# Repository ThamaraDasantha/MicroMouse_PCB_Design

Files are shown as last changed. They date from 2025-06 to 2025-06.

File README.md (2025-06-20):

# 🐭 Micromouse Robot – Custom PCB Design

This repository contains the **custom PCB design** for a Micromouse autonomous maze-solving robot. The design was inspired by the **Green Giant Micromouse**, a popular open-source project, and has been tailored to support modular, scalable, and competition-ready robotic development.

---

## 📦 Project Summary

Micromouse robots are small autonomous vehicles designed to solve mazes as quickly as possible. This PCB is the main controller board for such a robot, integrating motor drivers, sensors, power management, and microcontroller components in a compact footprint.

This design builds upon the **Green Giant Micromouse** architecture, with improvements for component sourcing, layout optimization, and modularity for further development.

---

## 🧠 Features & Specifications

| Category | Description |
|---|---|
| **Microcontroller** | STM32F4 / STM32F1 series (footprint supports both) |
| **Motor Drivers** | DRV8833 Dual H-Bridge for 2 DC motors |
| **Sensors** | IR distance sensors (front, left, right, 45 digree) – 5 sensors |
| **Power System** | 2-cell Li-ion with step-down regulator (5V and 3.3V rails)|
| **Connectivity** | Serial debug headers, encoder inputs, IR TX/RX support |
| **Form Factor** | Compact 2-layer PCB, optimized for wheel/motor layout |
| **Reference Design** | Based on Green Giant Micromouse with custom adaptations |

---

## 📐 PCB Design Overview

- Designed using **Eagle**
- Two-layer layout with clear separation of power and logic
- Silkscreen indicators for debugging and easy assembly
- Power and signal decoupling capacitors for noise stability
- Modular connector options for plugging in sensors and actuators

---

## 🧪 Testing & Next Steps

- Motor driver tested with small DC gear motors (30:1)
- Voltage rails tested with onboard regulators (5V and 3.3V)
- IR sensors and encoders interfaced with STM32 test code
- Future integration: PID motor control, maze-solving algorithm, IMU

---

## 📝 Acknowledgment

This design is heavily inspired by the [Green Giant Micromouse](https://github.com/davidtavarez/green-giant) project and adapted for educational and competitive use.

---

## 👨‍💻 Author

**Thamara Banneheka**  
Embedded Systems & Robotics Enthusiast  
📧 thamaradasantha@gmail.com  
🔗 [LinkedIn](https://www.linkedin.com/in/thamara-dasantha-banneheka/)

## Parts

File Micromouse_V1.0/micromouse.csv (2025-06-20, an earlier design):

Qty | Value | Device | Package | Parts | Description | ARROW_PART_NUMBER | ARROW_PRICE-STOCK | AVAILABILITY | CATEGORY | DESCRIPTION | HEIGHT | MANUFACTURER | MANUFACTURER_NAME | MANUFACTURER_PART_NUMBER | MF | MOUSER_PART_NUMBER | MOUSER_PRICE-STOCK | MP | MPN | OC_FARNELL | OC_NEWARK | OPERATING_TEMP | OPERATING_TEMPERATURE | PACKAGE | PART_STATUS | POPULARITY | PRICE | PROD_ID | RATING | ROHS_COMPLIANT | SERIES | SF_SKU | SPICEPREFIX | SUB-CATEGORY | SUB_CATEGORY | THERMALLOSS | TOLERANCE | TYPE | VALUE | VOLTAGE_RATING
1 |  | CONN_04X2 | 2X4 | J4 | Multi connection point. Often used as Generic Header-pin footprint for 0.1 inch spaced/style header connections
2 |  | JP1Q | JP1 | JP1, JP2 | JUMPER |  |  |  |  |  |  |  |  |  |  |  |  |  |  |  |  |  |  |  |  | 15
6 |  | LED0603 | LED-0603 | D11, D14, D17, D20, D22, D23 | LED (Generic)
2 |  | MA03-2 | MA03-2 | J2, J3 | PIN HEADER |  |  |  |  |  |  |  |  |  |  |  |  |  |  | unknown | unknown |  |  |  |  | 15
1 |  | PINHD-1X6 | 1X06 | JP3 | PIN HEADER
1 |  | SWITCH-SPDT-PTH-11.6X4.0MM | SWITCH_SPDT_PTH_11.6X4.0MM | S2 | Single Pole, Double Throw (SPDT) Switch |  |  |  |  |  |  |  |  |  |  |  |  |  |  |  |  |  |  |  |  |  |  | SWCH-08261 |  |  |  | COM-00102
1 | 0.01uF | C_CHIP-0805(2012-METRIC) | CAPC2012X110 | C_G1 | Capacitor - Generic |  |  |  | Capacitor
17 | 0.1uF | C_CHIP-0805(2012-METRIC) | CAPC2012X110 | C_5V4_4, C_EM2, C_EM3, C_EM5, C_EM7, C_EM10, C_EM12, C_G2, C_G3, C_M1, C_M5, C_RST, C_V1, C_V2, C_V3, C_V4, C_VA2 | Capacitor - Generic |  |  |  | Capacitor
17 | 0.1uf | C_CHIP-0805(2012-METRIC) | CAPC2012X110 | C3.3V_1, C5V_1, C5V_2, C5V_3, C5V_4, CNR, C_3.3V_6, C_A3.3V_1, C_A3.3V_3, C_B2, C_B3, C_B4, C_B7, C_DSP2, C_VBAT1, C_VBAT2, C_VBAT3 | Capacitor - Generic |  |  |  | Capacitor
5 | 0.75 ohm | R_CHIP-0603(1608-METRIC) | RESC1608X60 | R_R8, R_R10, R_R12, R_R14, R_R17 | Resistor Fixed - Generic |  |  |  | Resistor |  |  |  |  |  |  |  |  |  |  |  |  |  |  |  |  |  |  |  |  |  |  |  | R | Fixed
4 | 1.8k | R_CHIP-0603(1608-METRIC) | RESC1608X60 | R_R2, R_R4, R_R6, R_R7 | Resistor Fixed - Generic |  |  |  | Resistor |  |  |  |  |  |  |  |  |  |  |  |  |  |  |  |  |  |  |  |  |  |  |  | R | Fixed
1 | 10 uH | L-USL4035M | L4035M | L1 | INDUCTOR, American symbol |  |  |  |  |  |  |  |  |  |  |  |  |  |  |  |  |  |  |  |  | 0 |  |  |  |  |  |  | L
1 | 100K | R_CHIP-0603(1608-METRIC) | RESC1608X60 | R_B1 | Resistor Fixed - Generic |  |  |  | Resistor |  |  |  |  |  |  |  |  |  |  |  |  |  |  |  |  |  |  |  |  |  |  |  | R | Fixed
2 | 100uF | C_CHIP-0805(2012-METRIC) | CAPC2012X110 | C_MB_L, C_MB_R | Capacitor - Generic |  |  |  | Capacitor
1 | 100uf | C_CHIP-0805(2012-METRIC) | CAPC2012X110 | C_5V_1 | Capacitor - Generic |  |  |  | Capacitor
2 | 10K | R_CHIP-0603(1608-METRIC) | RESC1608X60 | R_B5, R_PG1 | Resistor Fixed - Generic |  |  |  | Resistor |  |  |  |  |  |  |  |  |  |  |  |  |  |  |  |  |  |  |  |  |  |  |  | R | Fixed
16 | 10k | R_CHIP-0603(1608-METRIC) | RESC1608X60 | R_FBB2, R_LED1_PULLUP, R_LED1_PULLUP1, R_LED1_PULLUP2, R_LED1_PULLUP3, R_PWMUP3, R_PWMUP4, R_PWMUP_1, R_PWMUP_2, R_R9, R_R11, R_R13, R_R15, R_R16, R_R18, R_VM2 | Resistor Fixed - Generic |  |  |  | Resistor |  |  |  |  |  |  |  |  |  |  |  |  |  |  |  |  |  |  |  |  |  |  |  | R | Fixed
1 | 10uF | C_CHIP-0805(2012-METRIC) | CAPC2012X110 | C_EM11 | Capacitor - Generic |  |  |  | Capacitor
1 | 10uH | L-USL4035M | L4035M | L3 | INDUCTOR, American symbol |  |  |  |  |  |  |  |  |  |  |  |  |  |  |  |  |  |  |  |  | 0 |  |  |  |  |  |  | L
4 | 10uf | C_CHIP-0805(2012-METRIC) | CAPC2012X110 | C3.3V_7, C_3.3V_5, C_DSP1, C_DSP3 | Capacitor - Generic |  |  |  | Capacitor
1 | 115K | R_CHIP-0603(1608-METRIC) | RESC1608X60 | RB1 | Resistor Fixed - Generic |  |  |  | Resistor |  |  |  |  |  |  |  |  |  |  |  |  |  |  |  |  |  |  |  |  |  |  |  | R | Fixed
1 | 150K | R_CHIP-0603(1608-METRIC) | RESC1608X60 | R_B2 | Resistor Fixed - Generic |  |  |  | Resistor |  |  |  |  |  |  |  |  |  |  |  |  |  |  |  |  |  |  |  |  |  |  |  | R | Fixed
3 | 1K | R_CHIP-0603(1608-METRIC) | RESC1608X60 | R_LED8, R_LED9, R_PWR1 | Resistor Fixed - Generic |  |  |  | Resistor |  |  |  |  |  |  |  |  |  |  |  |  |  |  |  |  |  |  |  |  |  |  |  | R | Fixed
1 | 1N4148WSQ-13-F | 1N4148WSQ-13-F | SOD2513X120N | D7 | SURFACE MOUNT FAST SWITCHING DIODE | 1N4148WSQ-13-F | https://www.arrow.com/en/products/1n4148wsq-13-f/diodes-incorporated |  |  | SURFACE MOUNT FAST SWITCHING DIODE | 1.2mm |  | Diodes Inc. | 1N4148WSQ-13-F |  | N/A | https://www.mouser.com/Search/Refine.aspx?Keyword=N%2FA
1 | 2.2 uH | L-USL4035M | L4035M | L6 | INDUCTOR, American symbol |  |  |  |  |  |  |  |  |  |  |  |  |  |  |  |  |  |  |  |  | 0 |  |  |  |  |  |  | L
10 | 2.2uF | C_CHIP-0805(2012-METRIC) | CAPC2012X110 | C_BAT, C_G4, C_VA1, C_VA3, C_VA4, C_VA6, C_VA8, C_VA9, C_VCAP1, C_VCAP2 | Capacitor - Generic |  |  |  | Capacitor
2 | 2.2uf | C_CHIP-0805(2012-METRIC) | CAPC2012X110 | C_A3.3V, C_B5 | Capacitor - Generic |  |  |  | Capacitor
1 | 22 pf | C_CHIP-0805(2012-METRIC) | CAPC2012X110 | C_B10 | Capacitor - Generic |  |  |  | Capacitor
1 | 223K | R_CHIP-0603(1608-METRIC) | RESC1608X60 | RT1 | Resistor Fixed - Generic |  |  |  | Resistor |  |  |  |  |  |  |  |  |  |  |  |  |  |  |  |  |  |  |  |  |  |  |  | R | Fixed
5 | 330 ohm | R_CHIP-0603(1608-METRIC) | RESC1608X60 | R_LED1, R_LED2, R_LED3, R_LED4, R_LED7 | Resistor Fixed - Generic |  |  |  | Resistor |  |  |  |  |  |  |  |  |  |  |  |  |  |  |  |  |  |  |  |  |  |  |  | R | Fixed
1 | 3300pF | C_CHIP-0805(2012-METRIC) | CAPC2012X110 | C_SS1 | Capacitor - Generic |  |  |  | Capacitor
1 | 35.7K | R_CHIP-0603(1608-METRIC) | RESC1608X60 | R_B3 | Resistor Fixed - Generic |  |  |  | Resistor |  |  |  |  |  |  |  |  |  |  |  |  |  |  |  |  |  |  |  |  |  |  |  | R | Fixed
1 | 3A/250V | B2B-XH-A | B2B-XH-A | J1 | XH Connector Top Entry - 2POS |  |  |  | CONNECTOR | 2.5mm pitch/disconnectable crimp style connector |  | JST (XH CONNECTOR) |  |  |  |  |  |  | B2B-XH-A |  |  |  | -25°C ~ 85°C |  | ACTIVE |  |  |  |  | COMPLIANT | B_B-XH-A |  | B |  | Through hole connector |  |  | top entry | 3A/250V
5 | 4.7 uH | L-USL4035M | L4035M | L2, L4, L5, L7, XFL4020 | INDUCTOR, American symbol |  |  |  |  |  |  |  |  |  |  |  |  |  |  |  |  |  |  |  |  | 0 |  |  |  |  |  |  | L
2 | 4.7k | R_CHIP-0603(1608-METRIC) | RESC1608X60 | R_R1, R_VM1 | Resistor Fixed - Generic |  |  |  | Resistor |  |  |  |  |  |  |  |  |  |  |  |  |  |  |  |  |  |  |  |  |  |  |  | R | Fixed
7 | 4.7uF | C_CHIP-0805(2012-METRIC) | CAPC2012X110 | C_EM1, C_EM4, C_EM6, C_EM8, C_EM9, C_M2, C_M4 | Capacitor - Generic |  |  |  | Capacitor
1 | 470 pf | C_CHIP-0805(2012-METRIC) | CAPC2012X110 | C_B6 | Capacitor - Generic |  |  |  | Capacitor
1 | 470uf | C_CHIP-0805(2012-METRIC) | CAPC2012X110 | CVC1 | Capacitor - Generic |  |  |  | Capacitor
1 | 47K | R_CHIP-0603(1608-METRIC) | RESC1608X60 | R_LED6 | Resistor Fixed - Generic |  |  |  | Resistor |  |  |  |  |  |  |  |  |  |  |  |  |  |  |  |  |  |  |  |  |  |  |  | R | Fixed
1 | 47uF | C_CHIP-0805(2012-METRIC) | CAPC2012X110 | C5V4_5 | Capacitor - Generic |  |  |  | Capacitor
5 | 47uf | C_CHIP-0805(2012-METRIC) | CAPC2012X110 | C3.3V_2, C_B1, C_B8, C_B9, C_VBAT4 | Capacitor - Generic |  |  |  | Capacitor
1 | 52.5K | R_CHIP-0603(1608-METRIC) | RESC1608X60 | R_FBT1 | Resistor Fixed - Generic |  |  |  | Resistor |  |  |  |  |  |  |  |  |  |  |  |  |  |  |  |  |  |  |  |  |  |  |  | R | Fixed
1 | 94.65K | R_CHIP-0603(1608-METRIC) | RESC1608X60 | R_B4 | Resistor Fixed - Generic |  |  |  | Resistor |  |  |  |  |  |  |  |  |  |  |  |  |  |  |  |  |  |  |  |  |  |  |  | R | Fixed
1 | GREEN | LEDCHIPLED_0603 | CHIPLED_0603 | PWR_LED1 | LED |  |  |  |  |  |  |  |  |  |  |  |  |  |  |  |  |  |  |  |  |  |  |  |  |  |  |  | B
1 | HCMS-2903 | HCMS-2903 | DIPS762W64P254L1778H508Q12N | DS1 | HCMS-2903 Avago 4 Digit Alphanumeric LED Display, 7 x 5 Dot Matrix Green 114 ucd 3.7mm |  |  |  |  | HCMS-2903 Avago 4 Digit Alphanumeric LED Display, 7 x 5 Dot Matrix Green 114 ucd 3.7mm | 5.08mm |  | Avago Technologies | HCMS-2903 |  | 630-HCMS-2903 | https://www.mouser.co.uk/ProductDetail/Broadcom-Avago/HCMS-2903?qs=xnajaXqBF98aIaDe8yGItA%3D%3D
2 | KMR211G | KMR211G | KMR211G | S1, S3 | Tactile Switch SPST-NO Top Actuated Surface Mount, Microminiature 40 N (8.8 lbs) during 25,000 cycles |  |  |  |  | Tactile Switch SPST-NO Top Actuated Surface Mount, Microminiature 40 N (8.8 lbs) during 25,000 cycles | 1.9mm |  | ITT CANNON | KMR211G
1 | LMZ10501SILR | LMZ10501SILR | SON65P260X300X150-9N | IC3 | Non-Isolated DC/DC Converters 1A Nano Mod w/ 5.5V Max Inpt VTG | LMZ10501SILR | https://www.arrow.com/en/products/lmz10501silr/texas-instruments |  |  | Non-Isolated DC/DC Converters 1A Nano Mod w/ 5.5V Max Inpt VTG | 1.5mm |  | Texas Instruments | LMZ10501SILR |  | 595-LMZ10501SILR | https://www.mouser.co.uk/ProductDetail/Texas-Instruments/LMZ10501SILR?qs=wqe5ZXqX%252B99mwpjk8%252BrPBA%3D%3D |  |  |  |  |  |  |  |  |  |  |  |  |  |  |  | X
1 | LMZ21701SILT | LMZ21701SILT | LMZ21701SILT | IC1 | 3V to 17V, 1A Step-Down DC/DC Power Module in 3.5mm 3.5mm Package | LMZ21701SILT | https://www.arrow.com/en/products/lmz21701silt/texas-instruments?region=nac |  |  | 3V to 17V, 1A Step-Down DC/DC Power Module in 3.5mm 3.5mm Package | 1.75mm |  | Texas Instruments | LMZ21701SILT |  | 595-LMZ21701SILT | https://www.mouser.co.uk/ProductDetail/Texas-Instruments/LMZ21701SILT?qs=%2Fd%252BFzHvH4c3T8wa09brf8Q%3D%3D |  |  |  |  |  |  |  |  |  |  |  |  |  |  |  | X
1 | MCP1700T-5002E_TT | MCP1700T-5002E_TT | SOT95P237X112-3N | IC4 | LDO Regulator 250mA 5.0V 1.6uA SOT23 | MCP1700T-5002E/TT | https://www.arrow.com/en/products/mcp1700t-5002ett/microchip-technology?region=nac |  |  | LDO Regulator 250mA 5.0V 1.6uA SOT23 | 1.12mm |  | Microchip | MCP1700T-5002E/TT |  | 579-MCP1700T5002E/TT | https://www.mouser.co.uk/ProductDetail/Microchip-Technology-Atmel/MCP1700T-5002E-TT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 |  |  |  |  |  |  |  |  |  |  |  |  |  |  |  | J
1 | MPU-6500 | MPU-6500 | QFN40P300X300X95-25N | IC7 | IMUs - Inertial Measurement Units 6-Axis MEMS MotionTracking Device with DMP | MPU-6500 | https://www.arrow.com/en/products/mpu-6500/invensense?region=nac |  |  | IMUs - Inertial Measurement Units 6-Axis MEMS MotionTracking Device with DMP | 0.95mm |  | TDK | MPU-6500 |  | 410-MPU-6500 | https://www.mouser.co.uk/ProductDetail/TDK-InvenSense/MPU-6500?qs=u4fy%2FsgLU9PiIOIlWOSPhQ%3D%3D
5 | SFH_4545 | SFH_4545 | DIO_SFH_4545 | D1, D2, D3, D4, D5 | High Power Infrared Emitter (940 nm) Check availability |  |  | In Stock |  | Infrared (IR) Emitter 950nm 1.5V 100mA 550mW/sr @ 100mA 10° Radial |  |  |  |  | OSRAM Opto |  |  | SFH 4545 |  |  |  |  |  | Radial Osram Opto |  |  | None
1 | SMT-0540-S-R | SMT-0540-S-R | SMT0540SR | LS1 | Speakers & Transducers SMD TRANSDUCER 3VP-P 100MA |  |  |  |  | Speakers & Transducers SMD TRANSDUCER 3VP-P 100MA | 2mm |  | PUI Audio | SMT-0540-S-R |  | 665-SMT0540SR | https://www.mouser.co.uk/ProductDetail/PUI-Audio/SMT-0540-S-R?qs=e16JbV5WBEu5VaDVzQP23Q%3D%3D
10 | SSM3K324R | SSM3K324R | SOT95P240X88-3N | Q10, Q11, Q12, Q13, Q14, Q15, Q18, Q19, Q20, Q21 | MOSFET N-Ch 4A SOT-23F-3 |  |  |  |  | MOSFET N-Ch 4A SOT-23F-3 | 0.88mm |  | Toshiba | SSM3K324R
1 | STM32F405RGT6V | STM32F405RGT6V | QFP50P1200X1200X160-64N | IC9 | STMicroelectronics, STM32F405RGT6V STM32F405RGT6V, 32 bit ARM Cortex M4 MCU 168MHz 1024 kB Flash, 192 + 4 kB RAM, USB CAN I2C 64-Pin LQFP | STM32F405RGT6V | https://www.arrow.com/en/products/stm32f405rgt6v/stmicroelectronics?region=nac |  |  | STMicroelectronics, STM32F405RGT6V STM32F405RGT6V, 32 bit ARM Cortex M4 MCU 168MHz 1024 kB Flash, 192 + 4 kB RAM, USB CAN I2C 64-Pin LQFP | 1.6mm |  | STMicroelectronics | STM32F405RGT6V |  | 511-STM32F405RGT6V | https://www.mouser.co.uk/ProductDetail/STMicroelectronics/STM32F405RGT6V?qs=gNDSiZmRJS%2FlL0isCSU2mg%3D%3D
5 | TEFT4300 | TEFT4300 | TEFT4300 | Q3, Q4, Q6, Q8, Q9 | Vishay TEFT4300 60 Infrared Phototransistor, Through-hole 3mm Package | TEFT4300 | https://www.arrow.com/en/products/teft4300/vishay |  |  | Vishay TEFT4300 60 Infrared Phototransistor, Through-hole 3mm Package | 6.1mm |  | Vishay | TEFT4300 |  | 782-TEFT4300 | https://www.mouser.co.uk/ProductDetail/Vishay-Semiconductors/TEFT4300?qs=HsFHTXumnCRbcrt8oPFPMA%3D%3D
1 | TPS61088RHLT | TPS61088RHLT | BQ24031IRHLRQ1 | IC8 | Texas Instruments TPS61088RHLT, 3, Boost Converter, Synchronous Boost Converter 10A 4.5 12.6 V, 2.2 MHz 20-Pin | TPS61088RHLT | https://www.arrow.com/en/products/tps61088rhlt/texas-instruments?region=nac |  |  | Texas Instruments TPS61088RHLT, 3, Boost Converter, Synchronous Boost Converter 10A 4.5 12.6 V, 2.2 MHz 20-Pin | 1mm |  | Texas Instruments | TPS61088RHLT |  | 595-TPS61088RHLT | https://www.mouser.co.uk/ProductDetail/Texas-Instruments/TPS61088RHLT?qs=MiqG6Kq1qKOeAwvWtl5eUw%3D%3D
1 | TPS73633MDBVREPG4 | TPS73633MDBVREPG4 | SOT95P280X145-5N | IC2 | LOW-DROPOUT REGULATORS | TPS73633MDBVREPG4 | https://www.arrow.com/en/products/tps73633mdbvrepg4/texas-instruments |  |  | LOW-DROPOUT REGULATORS | 1.45mm |  | Texas Instruments | TPS73633MDBVREPG4 |  | 595-PS73633MDBVREPG4 | https://www.mouser.co.uk/ProductDetail/Texas-Instruments/TPS73633MDBVREPG4?qs=OaSNdy%2FNfzkIGdo0ZU34AA%3D%3D |  |  |  |  |  |  |  |  |  |  |  |  |  |  |  | X
2 | UCC27524DR | UCC27524DR | SOIC127P600X175-8N | IC5, IC6 | Dual, 5A, High-Speed Low-Side Power MOSFET Driver | UCC27524DR | https://www.arrow.com/en/products/ucc27524dr/texas-instruments?region=nac |  |  | Dual, 5A, High-Speed Low-Side Power MOSFET Driver | 1.75mm |  | Texas Instruments | UCC27524DR |  | 595-UCC27524DR | https://www.mouser.co.uk/ProductDetail/Texas-Instruments/UCC27524DR?qs=iuXUNOC6nYdK8rrTqka0jA%3D%3D
2 | ZXMHC3F381N8TC | ZXMHC3F381N8TC | SOIC127P600X175-8N | Q1, Q2 | MOSFET Dual N/P-Ch 30V 4.98A/4.13A SOIC8 Diodes Inc ZXMHC3F381N8TC Quad N/P-channel MOSFET Transistor, 8-Pin SO | ZXMHC3F381N8TC | https://www.arrow.com/en/products/zxmhc3f381n8tc/diodes-incorporated?region=nac |  |  | MOSFET Dual N/P-Ch 30V 4.98A/4.13A SOIC8 Diodes Inc ZXMHC3F381N8TC Quad N/P-channel MOSFET Transistor, 8-Pin SO | 1.75mm |  | Diodes Inc. | ZXMHC3F381N8TC |  | 522-ZXMHC3F381N8TC | https://www.mouser.co.uk/ProductDetail/Diodes-Incorporated/ZXMHC3F381N8TC?qs=7E5rbXJDVJoJr15tcLBfrA%3D%3D

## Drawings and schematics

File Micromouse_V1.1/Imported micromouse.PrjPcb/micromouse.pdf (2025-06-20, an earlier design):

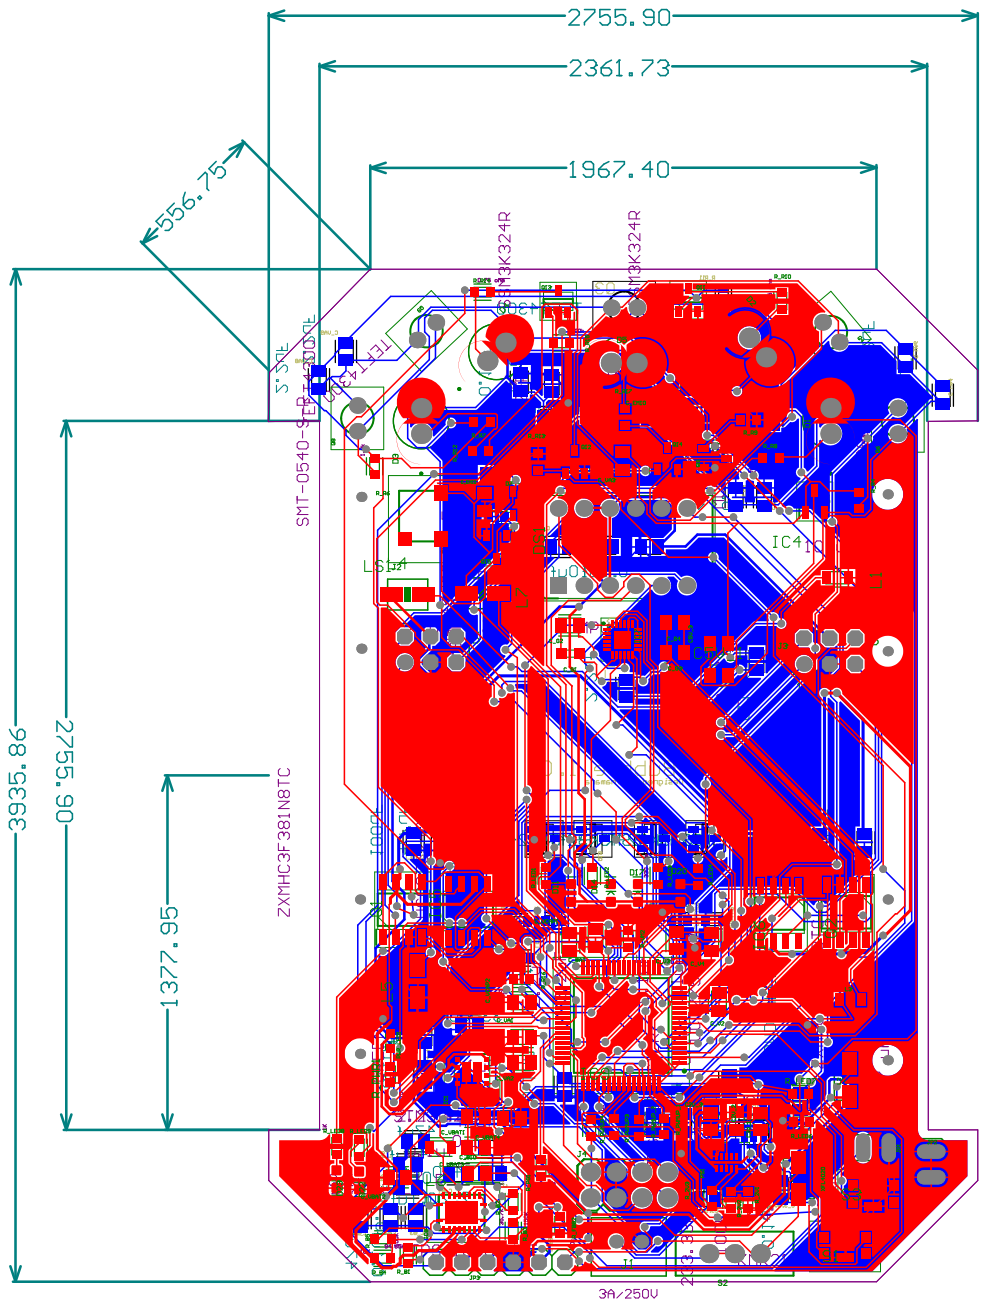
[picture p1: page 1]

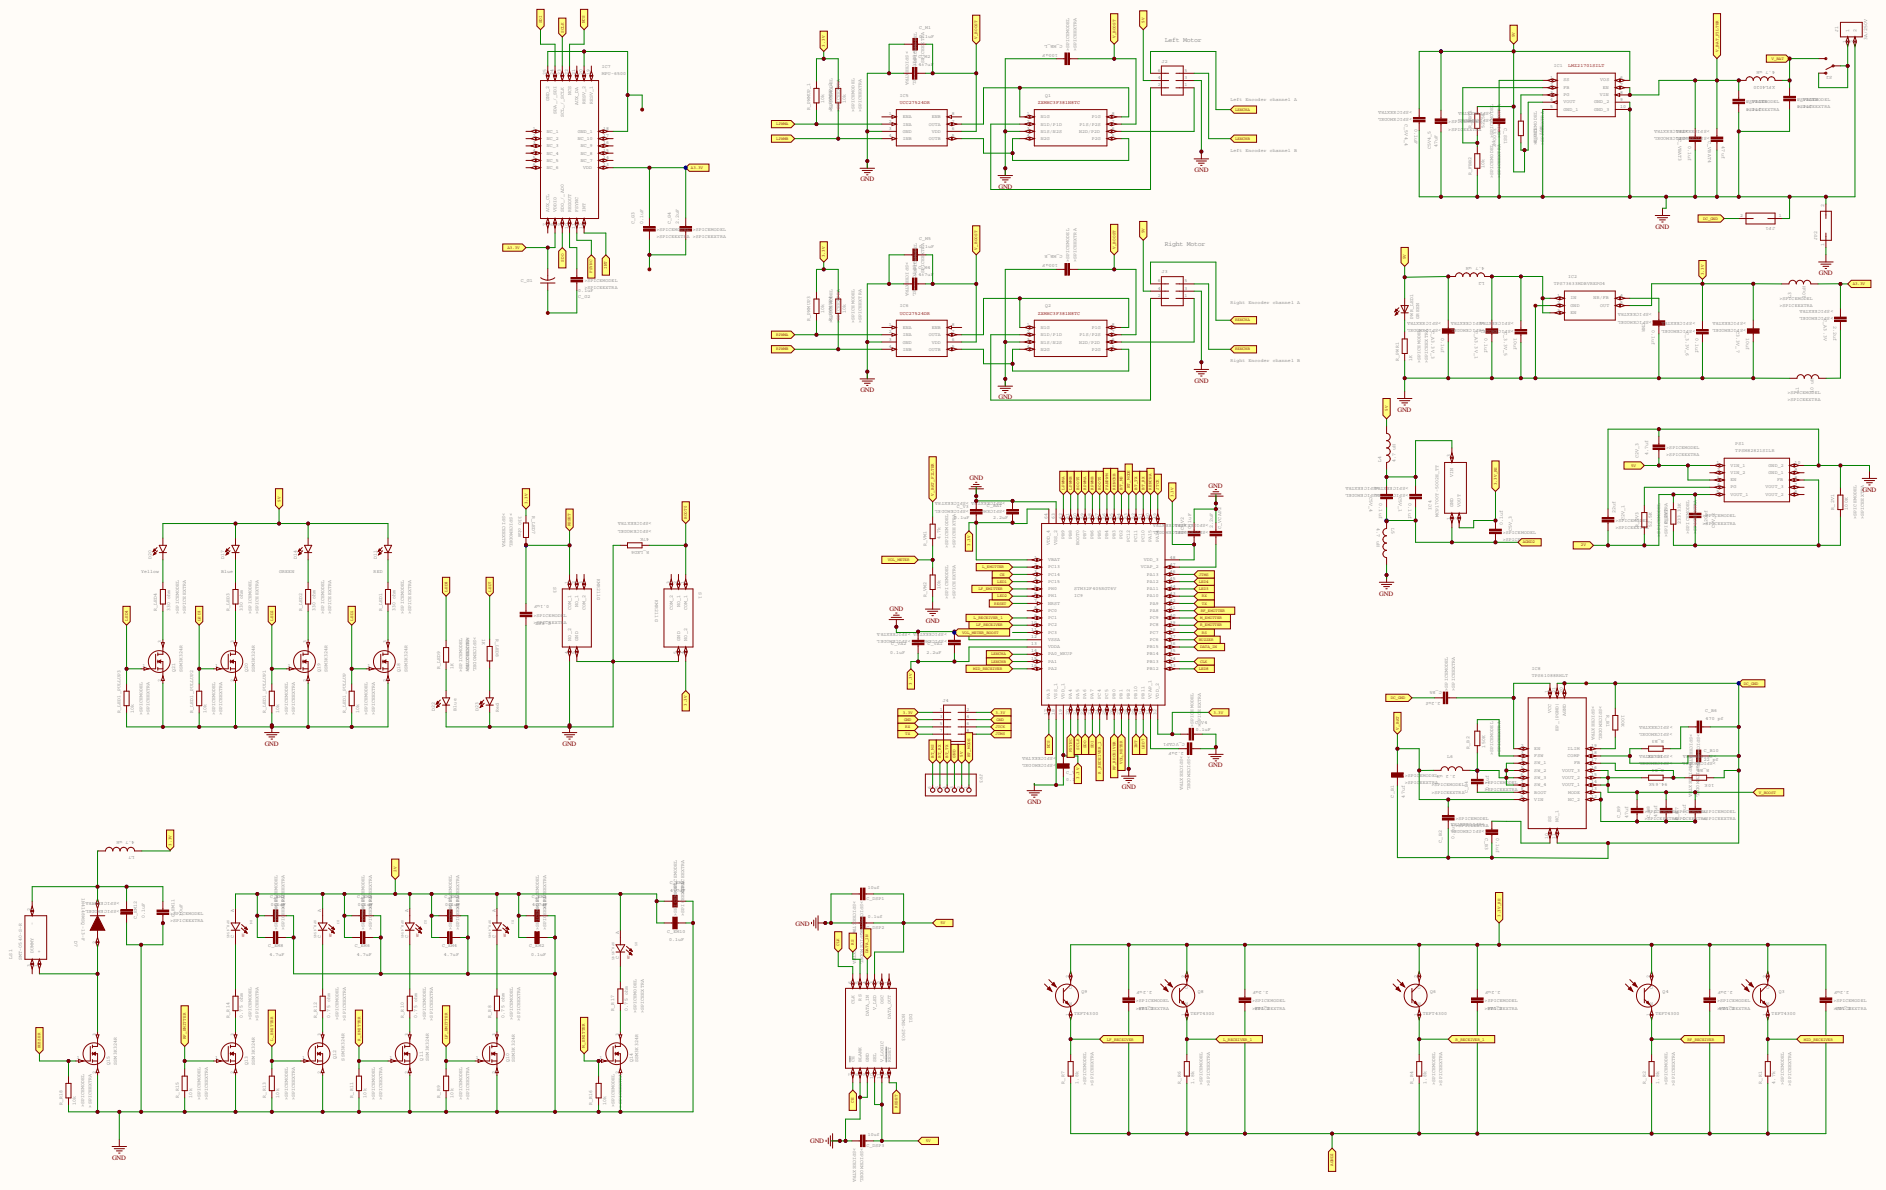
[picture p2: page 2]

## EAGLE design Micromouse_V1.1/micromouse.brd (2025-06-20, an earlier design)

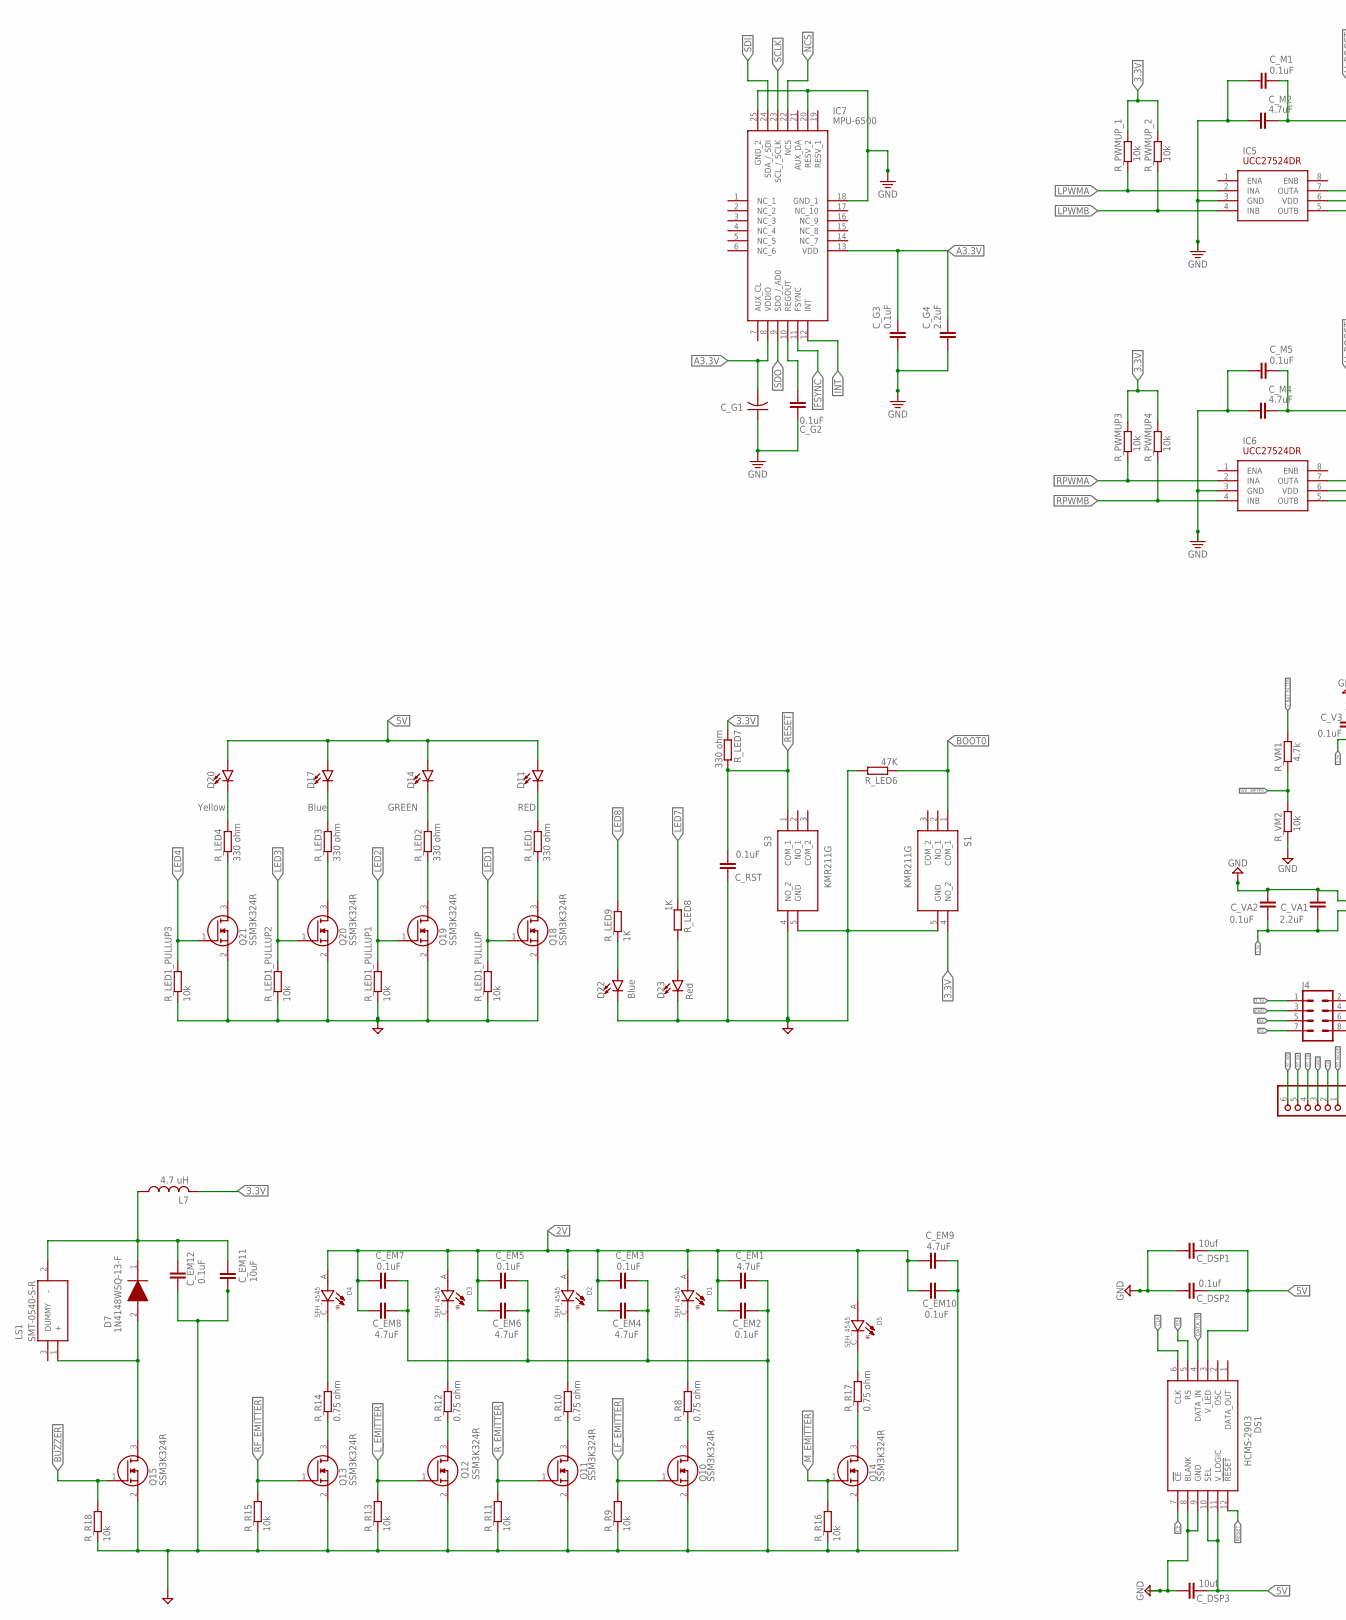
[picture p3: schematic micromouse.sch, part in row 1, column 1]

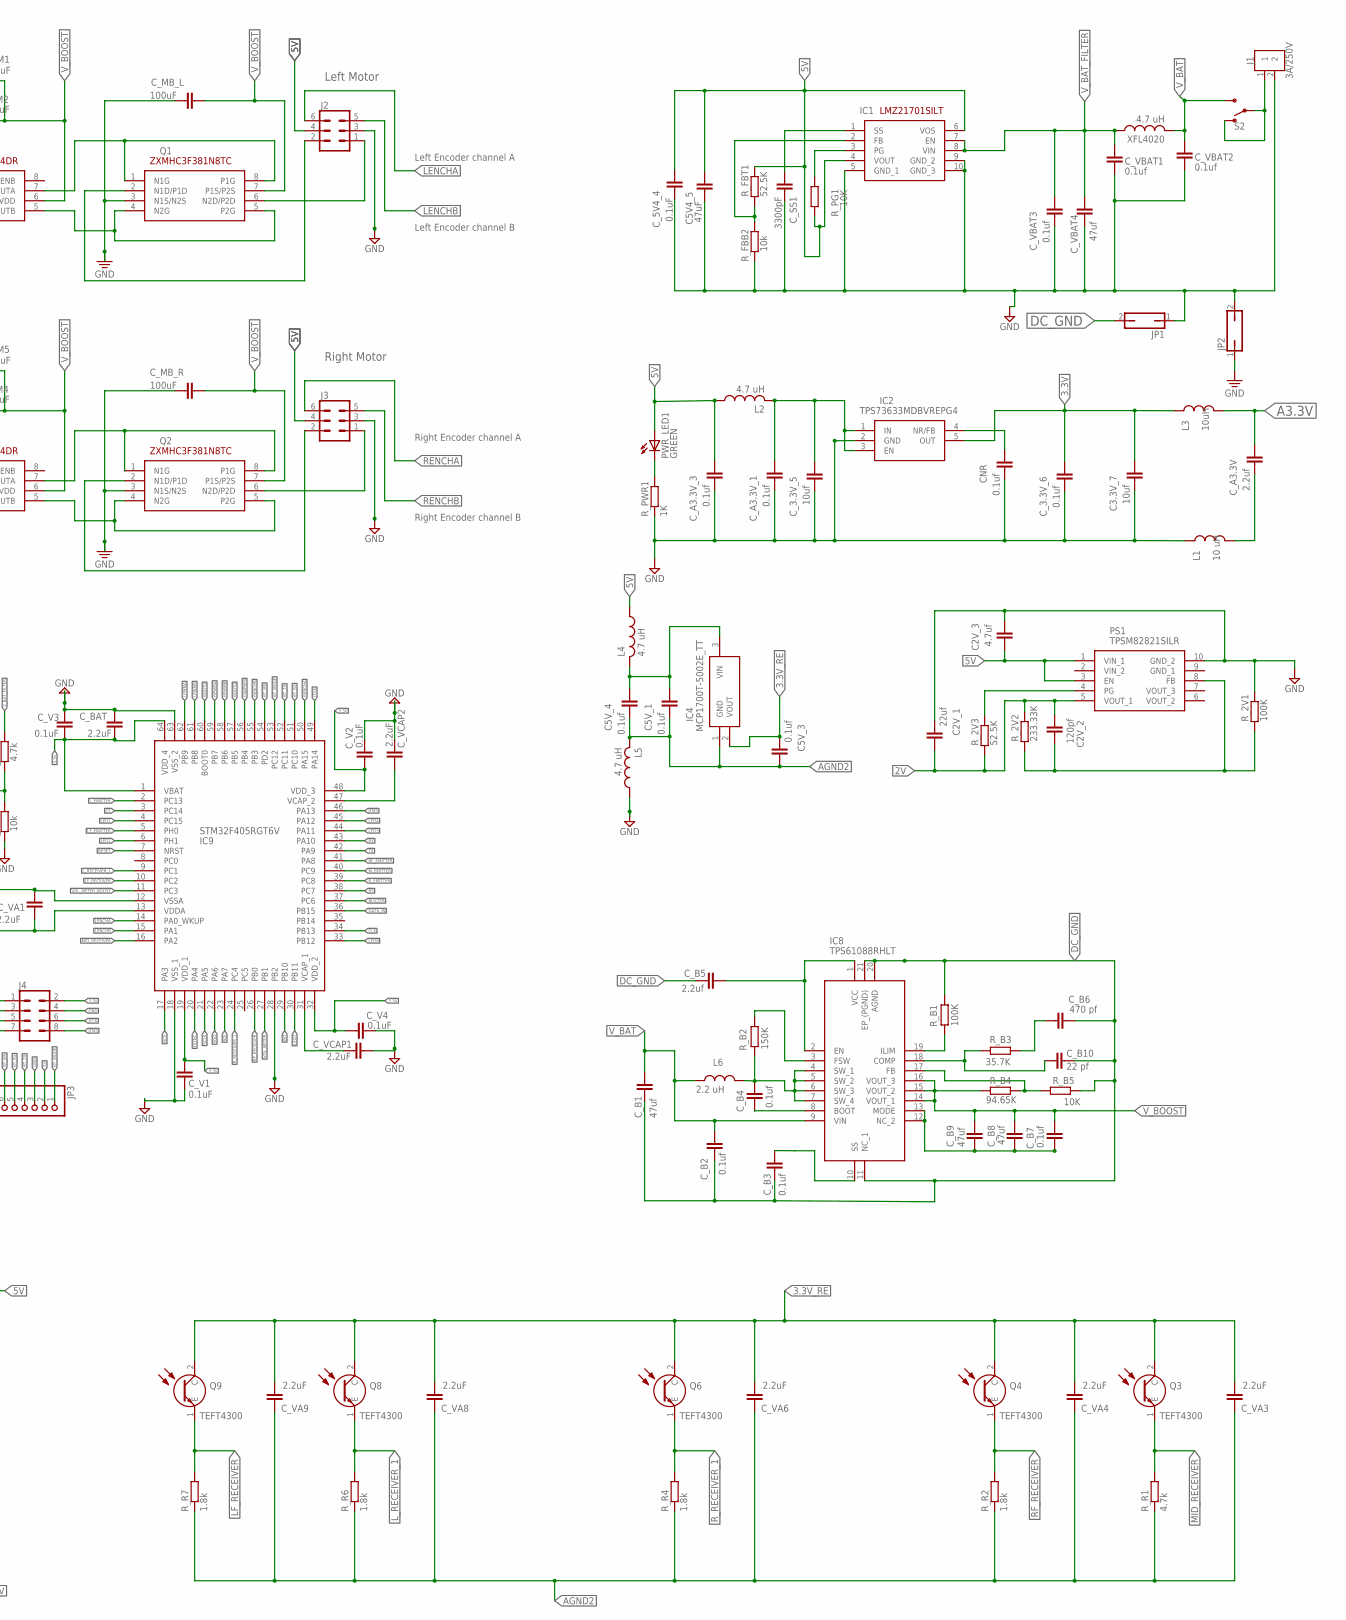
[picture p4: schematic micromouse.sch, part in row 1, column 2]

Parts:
C2V_1: 22uf; CAPC2012X110
C2V_2: 120pf; CAPC2012X110
C2V_3: 4.7uf; CAPC2012X110
C3.3V_7: 10uf; CAPC2012X110
C5V4_5: 47uF; CAPC2012X110
C5V_1, C5V_3, C5V_4: 0.1uf; CAPC2012X110
CNR: 0.1uf; CAPC2012X110
C_3.3V_5: 10uf; CAPC2012X110
C_3.3V_6: 0.1uf; CAPC2012X110
C_5V4_4: 0.1uF; CAPC2012X110
C_A3.3V: 2.2uf; CAPC2012X110
C_A3.3V_1, C_A3.3V_3: 0.1uf; CAPC2012X110
C_B1, C_B8, C_B9: 47uf; CAPC2012X110
C_B2, C_B3, C_B4, C_B7: 0.1uf; CAPC2012X110
C_B5: 2.2uf; CAPC2012X110
C_B6: 470 pf; CAPC2012X110
C_B10: 22 pf; CAPC2012X110
C_BAT: 2.2uF; CAPC2012X110
C_DSP1, C_DSP3: 10uf; CAPC2012X110
C_DSP2: 0.1uf; CAPC2012X110
C_EM1, C_EM4, C_EM6, C_EM8, C_EM9: 4.7uF; CAPC2012X110
C_EM2, C_EM3, C_EM5, C_EM7, C_EM10, C_EM12: 0.1uF; CAPC2012X110
C_EM11: 10uF; CAPC2012X110
C_G1: 0.01uF; C0603K
C_G2, C_G3: 0.1uF; CAPC2012X110
C_G4: 2.2uF; CAPC2012X110
C_M1, C_M5: 0.1uF; CAPC2012X110
C_M2, C_M4: 4.7uF; CAPC2012X110
C_MB_L: 100uF; CAPC2012X110
C_MB_R: 100uF; CAPC2012X110
C_RST: 0.1uF; CAPC2012X110
C_SS1: 3300pF; CAPC2012X110
C_V1, C_V2, C_V3, C_V4: 0.1uF; CAPC2012X110
C_VA1, C_VA3, C_VA4, C_VA6, C_VA8, C_VA9: 2.2uF; CAPC2012X110
C_VA2: 0.1uF; CAPC2012X110
C_VBAT1, C_VBAT2, C_VBAT3: 0.1uf; CAPC2012X110
C_VBAT4: 47uf; CAPC2012X110
C_VCAP1, C_VCAP2: 2.2uF; CAPC2012X110
D1, D2, D3, D4, D5: SFH_4545; DIO_SFH_4545
D7: 1N4148WSQ-13-F; SOD2513X120N
D11, D14, D17, D20, D22, D23: LED0603; LED-0603
DS1: HCMS-2903; DIPS762W64P254L1778H508Q12N
IC1: LMZ21701SILT
IC2: TPS73633MDBVREPG4; SOT95P280X145-5N
IC4: MCP1700T-5002E_TT; SOT95P237X112-3N
IC5, IC6: UCC27524DR; SOIC127P600X175-8N
IC7: MPU-6500; QFN40P300X300X95-25N
IC8: TPS61088RHLT; BQ24031IRHLRQ1
IC9: STM32F405RGT6V; QFP50P1200X1200X160-64N
J1: 3A/250V; B2B-XH-A
J2, J3: MA03-2
J4: CONN_04X2; 2X4
JP1, JP2: JP1Q; JP1
JP3: PINHD-1X6; 1X06
L1: 10 uH; INDC2009X120
L2, L4, L5, L7: 4.7 uH; L4035M
L3: 10uH; INDC2009X120
L6: 2.2 uH; INDC2009X120
LS1: SMT-0540-S-R; SMT0540SR
PS1: TPSM82821SILR
PWR_LED1: GREEN; CHIPLED_0603
Q1, Q2: ZXMHC3F381N8TC; SOIC127P600X175-8N
Q3, Q4, Q6, Q8, Q9: TEFT4300
Q10, Q11, Q12, Q13, Q14, Q15, Q18, Q19, Q20, Q21: SSM3K324R; SOT95P240X88-3N
R_2V1: 100K; RESC1608X60
R_2V2: 233.33K; RESC1608X60
R_2V3: 52.5K; RESC1608X60
R_B1: 100K; RESC1608X60
R_B2: 150K; RESC1608X60
R_B3: 35.7K; RESC1608X60
R_B4: 94.65K; RESC1608X60
R_B5: 10K; RESC1608X60
R_FBB2: 10k; RESC1608X60
R_FBT1: 52.5K; RESC1608X60
R_LED1, R_LED2, R_LED3, R_LED4, R_LED7: 330 ohm; RESC1608X60
R_LED1_PULLUP, R_LED1_PULLUP1, R_LED1_PULLUP2, R_LED1_PULLUP3: 10k; RESC1608X60
R_LED6: 47K; RESC1608X60
R_LED8, R_LED9: 1K; RESC1608X60
R_PG1: 10K; RESC1608X60
R_PWMUP3, R_PWMUP4: 10k; RESC1608X60
R_PWMUP_1, R_PWMUP_2: 10k; RESC1608X60
R_PWR1: 1K; RESC1608X60
R_R1: 4.7k; RESC1608X60
R_R2, R_R4, R_R6, R_R7: 1.8k; RESC1608X60
R_R8, R_R10, R_R12, R_R14, R_R17: 0.75 ohm; RESC1608X60
R_R9, R_R11, R_R13, R_R15, R_R16, R_R18: 10k; RESC1608X60
R_VM1: 4.7k; RESC1608X60
R_VM2: 10k; RESC1608X60
S1, S3: KMR211G
S2: SWITCH-SPDT-PTH-11.6X4.0MM; SWITCH_SPDT_PTH_11.6X4.0MM
XFL4020: 4.7 uH; L4035M

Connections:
2V: C2V_1.2, C2V_2.1, C_EM1.1, C_EM2.1, C_EM3.1, C_EM4.1, C_EM5.1, C_EM6.1, C_EM7.1, C_EM8.1, C_EM9.1, C_EM10.1, D1.A, D2.A, D3.A, D4.A, D5.A, PS1.5 (VOUT_1), R_2V2.2, R_2V3.1
3.3V: C3.3V_7.2, C_3.3V_6.2, C_BAT.1, C_V1.2, C_V2.1, C_V3.1, C_V4.1, C_VA1.1, C_VA2.1, IC2.5 (OUT), IC9.1 (VBAT), IC9.13 (VDDA), IC9.19 (VDD_1), IC9.32 (VDD_2), IC9.48 (VDD_3), IC9.64 (VDD_4), J4.1, J4.2, L3.1, L7.2, R_LED7.1, R_PWMUP3.2, R_PWMUP4.2, R_PWMUP_1.2, R_PWMUP_2.2, S1.4 (NO_2)
3.3V_RE: C5V_3.1, C_VA3.1, C_VA4.1, C_VA6.1, C_VA8.1, C_VA9.1, IC4.2 (VOUT), Q3.2 (C), Q4.2 (C), Q6.2 (C), Q8.2 (C), Q9.2 (C)
5V: C2V_3.2, C5V4_5.1, C_5V4_4.2, C_A3.3V_3.2, C_DSP1.1, C_DSP2.1, C_DSP3.1, D11.A, D14.A, D17.A, D20.A, DS1.3 (V_LED), DS1.10 (SEL), DS1.11 (V_LOGIC), IC1.4 (VOUT), IC1.6 (VOS), J2.4, J3.4, JP3.2, L2.1, L4.1, PS1.1 (VIN_1), PS1.3 (EN), PWR_LED1.A, R_FBT1.2, R_PG1.1
A3.3V: C_A3.3V.2, C_G1.2, C_G3.1, C_G4.1, IC7.8 (VDDIO), IC7.13 (VDD), L3.2
AGND2: C5V_1.1, C5V_3.2, C5V_4.1, C_VA3.2, C_VA4.2, C_VA6.2, C_VA8.2, C_VA9.2, IC4.1 (GND), L5.2, R_R1.1, R_R2.1, R_R4.1, R_R6.1, R_R7.1
BOOT0: IC9.57 (PB5), IC9.60 (BOOT0), R_LED6.1, S1.1 (COM_1)
BT_MODE: IC9.53 (PC12), JP3.1
BT_MS: IC9.54 (PD2), JP3.6
BT_RX: IC9.51 (PC10), JP3.5
BT_TX: IC9.52 (PC11), JP3.4
BUZZER: IC9.37 (PC6), Q15.1 (G), R_R18.2
CE: DS1.7 (!CE), IC9.3 (PC14)
CLK: DS1.6 (CLK), IC9.34 (PB13)
DATA_IN: DS1.4 (DATA_IN), IC9.36 (PB15)
DC_GND: C_B1.2, C_B2.2, C_B3.1, C_B5.1, C_B6.1, C_B10.1, IC8.11 (NC_1), IC8.20 (AGND), IC8.21 (EP_(PGND)), JP1.2, R_B1.1, R_B5.1
FANPWM: IC9.56 (PB4)
FSYNC: IC7.11 (FSYNC), IC9.20 (PA4)
GND: C2V_1.1, C2V_3.1, C3.3V_7.1, C5V4_5.2, CNR.1, C_3.3V_5.1, C_3.3V_6.1, C_5V4_4.1, C_A3.3V_1.1, C_A3.3V_3.1, C_BAT.2, C_DSP1.2, C_DSP2.2, C_DSP3.2, C_EM1.2, C_EM2.2, C_EM3.2, C_EM4.2, C_EM5.2, C_EM6.2, C_EM7.2, C_EM8.2, C_EM9.2, C_EM10.2, C_EM11.2, C_EM12.1, C_M1.2, C_M2.1, C_M4.1, C_M5.2, C_MB_L.1, C_MB_R.1, C_RST.2, C_SS1.1, C_V1.1, C_V2.2, C_V3.2, C_V4.2, C_VA1.2, C_VA2.2, C_VBAT1.2, C_VBAT2.2, C_VBAT3.1, C_VBAT4.1, C_VCAP1.1, C_VCAP2.2, D22.C, D23.C, DS1.8 (BLANK), DS1.9 (GND), IC1.5 (GND_1), IC1.9 (GND_2), IC1.10 (GND_3), IC2.2 (GND), IC5.3 (GND), IC6.3 (GND), IC9.12 (VSSA), IC9.18 (VSS_1), IC9.28 (PB2), IC9.63 (VSS_2), J1.2, J2.3, J3.3, J4.3, J4.4, JP1.1, JP2.1, JP2.2, JP3.3, L1.1, L5.1, PS1.10 (GND_2), Q1.3 (N1S/N2S), Q2.3 (N1S/N2S), Q10.2 (S), Q11.2 (S), Q12.2 (S), Q13.2 (S), Q14.2 (S), Q15.2 (S), Q18.2 (S), Q19.2 (S), Q20.2 (S), Q21.2 (S), R_2V1.2, R_FBB2.1, R_LED1_PULLUP.1, R_LED1_PULLUP1.1, R_LED1_PULLUP2.1, R_LED1_PULLUP3.1, R_LED6.2, R_PWR1.1, R_R9.1, R_R11.1, R_R13.1, R_R15.1, R_R16.1, R_R18.1, R_VM2.1, S1.5 (GND), S3.4 (NO_2), S3.5 (GND)
INT: IC7.12 (INT), IC9.29 (PB10)
JTCK: IC9.49 (PA14), J4.6
JTMS: IC9.46 (PA13), J4.8
LED1: IC9.4 (PC15), Q18.1 (G), R_LED1_PULLUP.2
LED2: IC9.6 (PH1), Q19.1 (G), R_LED1_PULLUP1.2
LED3: IC9.44 (PA11), Q20.1 (G), R_LED1_PULLUP2.2
LED4: IC9.45 (PA12), Q21.1 (G), R_LED1_PULLUP3.2
LED7: IC9.30 (PB11), R_LED8.1
LED8: IC9.33 (PB12), R_LED9.2
LENCHA: IC9.14 (PA0_WKUP), J2.6
LENCHB: IC9.15 (PA1), J2.5
LF_EMITTER: IC9.5 (PH0), Q10.1 (G), R_R9.2
LF_RECEIVER: IC9.10 (PC2), Q9.1 (E), R_R7.2
LPWMA: IC5.2 (INA), IC9.62 (PB9), R_PWMUP_1.1
LPWMB: IC5.4 (INB), IC9.61 (PB8), R_PWMUP_2.1
L_EMITTER: IC9.2 (PC13), Q12.1 (G), R_R13.2
L_RECEIVER_1: IC9.9 (PC1), Q8.1 (E), R_R6.2
MID_RECEIVER: IC9.16 (PA2), Q3.1 (E), R_R1.2
M_EMITTER: IC9.40 (PC9), Q14.1 (G), R_R16.2
unnamed: C_SS1.2, IC1.1 (SS)
unnamed: IC5.7 (OUTA), Q1.1 (N1G), Q1.8 (P1G)
unnamed: IC1.3 (PG), R_PG1.2
unnamed: C_3.3V_5.2, C_A3.3V_1.2, IC2.1 (IN), IC2.3 (EN), L2.2
unnamed: PWR_LED1.C, R_PWR1.2
unnamed: IC1.2 (FB), R_FBB2.2, R_FBT1.1
unnamed: J1.1, S2.1 (O), S2.2
unnamed: CNR.2, IC2.4 (NR/FB)
unnamed: IC6.7 (OUTA), Q2.1 (N1G), Q2.8 (P1G)
unnamed: C5V_1.2, C5V_4.2, IC4.3 (VIN), L4.2
unnamed: C_A3.3V.1, L1.2
unnamed: IC6.5 (OUTB), Q2.4 (N2G), Q2.5 (P2G)
unnamed: IC5.5 (OUTB), Q1.4 (N2G), Q1.5 (P2G)
unnamed: J3.2, Q2.2 (N1D/P1D)
unnamed: J2.2, Q1.2 (N1D/P1D)
unnamed: J2.1, Q1.6 (N2D/P2D)
unnamed: J3.1, Q2.6 (N2D/P2D)
unnamed: IC7.18 (GND_1), IC7.20 (RESV_2), IC7.25 (GND_2)
unnamed: C_G3.2, C_G4.2
unnamed: C_G2.1, IC7.10 (REGOUT)
unnamed: C_G1.1, C_G2.2
unnamed: C_B3.2, IC8.10 (SS)
unnamed: C_B4.2, IC8.8 (BOOT)
unnamed: D1.C, R_R8.2
unnamed: C_B4.1, IC8.4 (SW_1), IC8.5 (SW_2), IC8.6 (SW_3), IC8.7 (SW_4), L6.2, R_B2.1
unnamed: IC8.19 (ILIM), R_B1.2
unnamed: C_B10.2, IC8.18 (COMP), R_B3.2
unnamed: IC8.3 (FSW), R_B2.2
unnamed: C_B5.2, IC8.1 (VCC), IC8.2 (EN)
unnamed: Q10.3 (D), R_R8.1
unnamed: C_B6.2, R_B3.1
unnamed: IC8.17 (FB), R_B4.1, R_B5.2
unnamed: Q14.3 (D), R_R17.1
unnamed: C_B7.2, C_B8.2, C_B9.2, IC8.12 (NC_2), IC8.13 (MODE)
unnamed: D5.C, R_R17.2
unnamed: D2.C, R_R10.2
unnamed: Q11.3 (D), R_R10.1
unnamed: C2V_2.2, PS1.8 (FB), R_2V1.1, R_2V2.1
unnamed: D7.2 (A), LS1.1 (+), Q15.3 (D)
unnamed: C_EM11.1, C_EM12.2, D7.1 (K), L7.1, LS1.2 (-)
unnamed: D3.C, R_R12.2
unnamed: Q12.3 (D), R_R12.1
unnamed: PS1.4 (PG), R_2V3.2
unnamed: C_VCAP2.1, IC9.47 (VCAP_2)
unnamed: D4.C, R_R14.2
unnamed: Q13.3 (D), R_R14.1
unnamed: C_VCAP1.2, IC9.31 (VCAP_1)
unnamed: Q18.3 (D), R_LED1.1
unnamed: D11.C, R_LED1.2
unnamed: Q19.3 (D), R_LED2.1
unnamed: D14.C, R_LED2.2
unnamed: D22.A, R_LED9.1
unnamed: Q20.3 (D), R_LED3.1
unnamed: D17.C, R_LED3.2
unnamed: D23.A, R_LED8.2
unnamed: Q21.3 (D), R_LED4.1
unnamed: D20.C, R_LED4.2
NCS: IC7.22 (NCS), IC9.17 (PA3)
RENCHA: IC9.50 (PA15), J3.6
RENCHB: IC9.55 (PB3), J3.5
RESET: C_RST.1, DS1.12 (!RESET), IC9.7 (NRST), R_LED7.2, S3.1 (COM_1)
RF_EMITTER: IC9.41 (PA8), Q13.1 (G), R_R15.2
RF_RECEIVER: IC9.26 (PB0), Q4.1 (E), R_R2.2
RPWMA: IC6.2 (INA), IC9.59 (PB7), R_PWMUP3.1
RPWMB: IC6.4 (INB), IC9.58 (PB6), R_PWMUP4.1
RS: DS1.5 (RS), IC9.38 (PC7)
RX: IC9.43 (PA10), J4.5
R_EMITTER: IC9.39 (PC8), Q11.1 (G), R_R11.2
R_RECEIVER_1: IC9.24 (PC4), Q6.1 (E), R_R4.2
SCLK: IC7.23 (SCL_/_SCLK), IC9.21 (PA5)
SDI: IC7.24 (SDA_/_SDI), IC9.23 (PA7)
SDO: IC7.9 (SDO_/_AD0), IC9.22 (PA6)
TX: IC9.42 (PA9), J4.7
VOL_METER: IC9.27 (PB1), R_VM1.1, R_VM2.2
VOL_METER_BOOST: IC9.11 (PC3)
V_BAT: C_B1.1, C_B2.1, C_VBAT2.1, IC8.9 (VIN), L6.1, S2.3 (S), XFL4020.2
V_BAT_FILTER: C_VBAT1.1, C_VBAT3.2, C_VBAT4.2, IC1.7 (EN), IC1.8 (VIN), R_VM1.2, XFL4020.1
V_BOOST: C_B7.1, C_B8.1, C_B9.1, C_M1.1, C_M2.2, C_M4.2, C_M5.1, C_MB_L.2, C_MB_R.2, IC5.6 (VDD), IC6.6 (VDD), IC8.14 (VOUT_1), IC8.15 (VOUT_2), IC8.16 (VOUT_3), Q1.7 (P1S/P2S), Q2.7 (P1S/P2S), R_B4.2

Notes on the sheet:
Left Motor
Right Motor
RED
GREEN
Blue
Yellow
Red
Right Encoder channel A
Right Encoder channel B
Left Encoder channel B
Left Encoder channel A

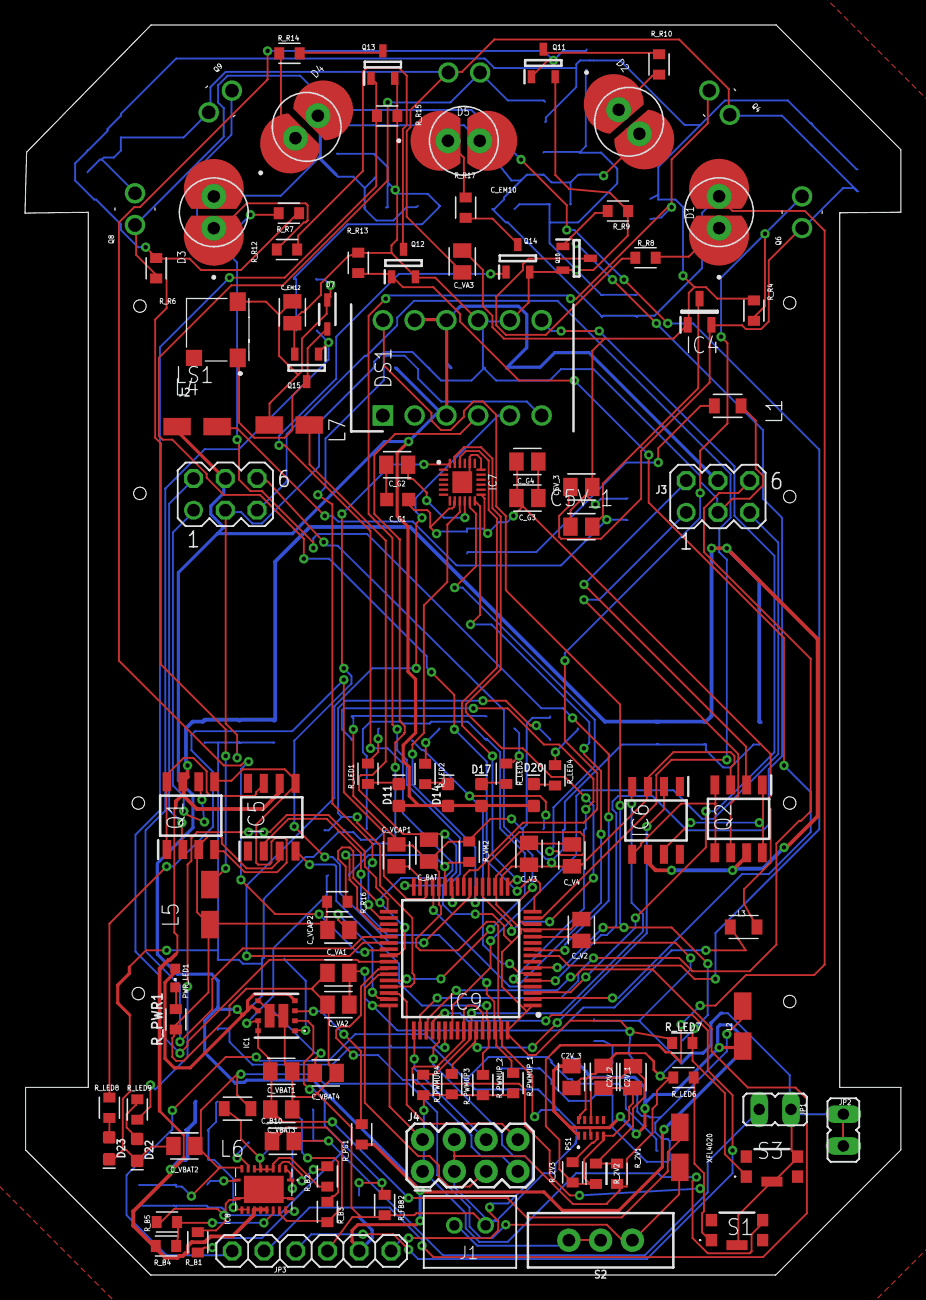
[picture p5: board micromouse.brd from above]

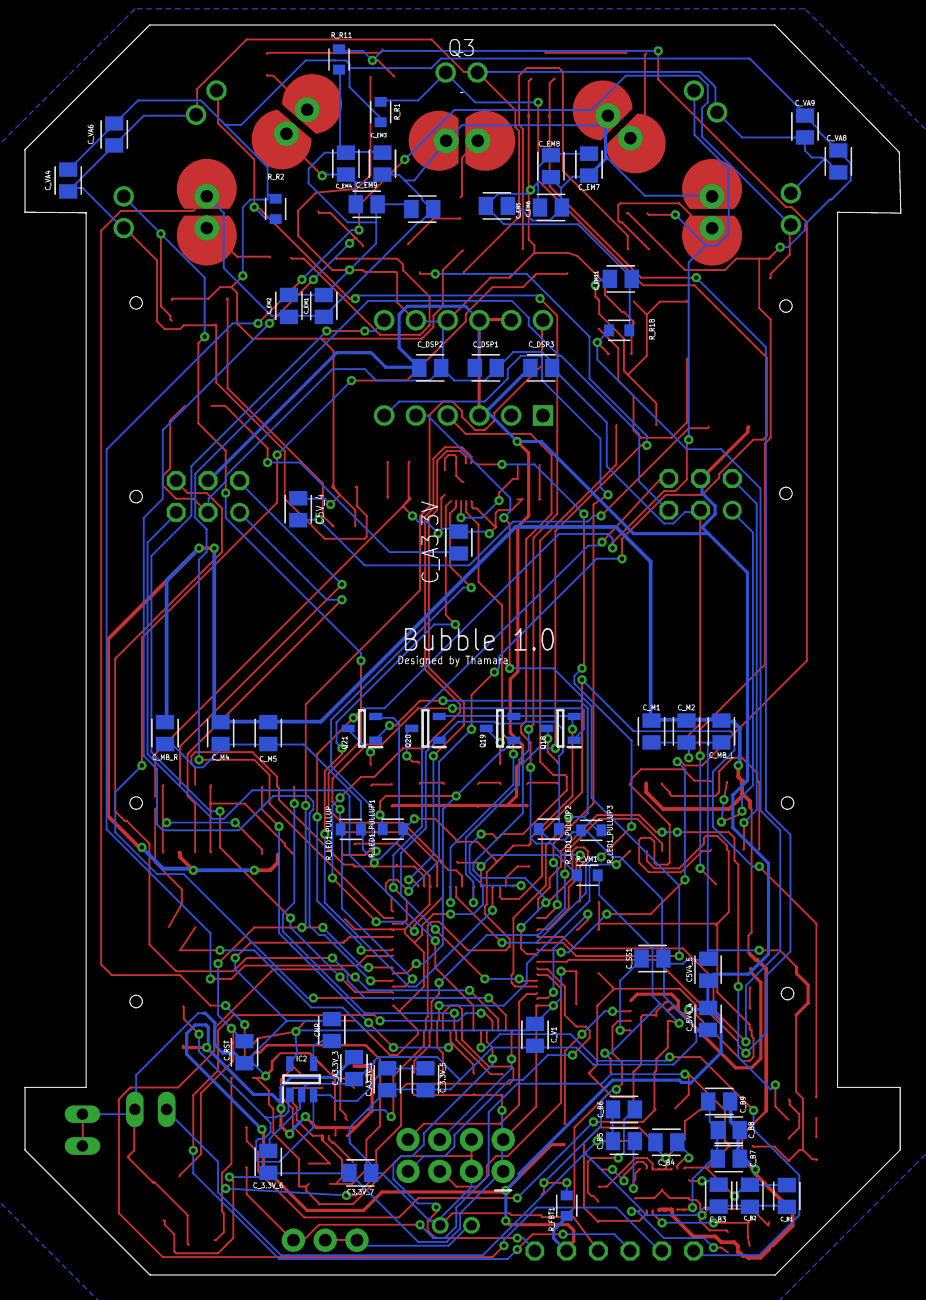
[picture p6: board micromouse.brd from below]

Board: 2 copper layers, 70.0 x 100.0 mm, 175 parts (62 on the bottom side), 114 nets.

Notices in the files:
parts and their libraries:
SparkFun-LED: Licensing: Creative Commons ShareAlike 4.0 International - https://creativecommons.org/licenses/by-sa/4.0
